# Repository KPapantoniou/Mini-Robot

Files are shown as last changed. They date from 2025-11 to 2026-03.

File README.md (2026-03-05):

### Modeling, Simulation, and Autonomous Control

> Master's Thesis — *K. Papantoniou*
> 📄 [Read the full thesis](presentation_thesis/thesis_KPapantoniou.pdf)

---

## What Is This?

Most robots move using wheels, legs, or tracks. This one moves using **vibrations**.

By spinning two small eccentric masses at controlled speeds, the robot generates asymmetric centrifugal forces that cause it to inch forward, backward, and rotate — with no conventional drivetrain. The result is an ultra-compact, mechanically simple platform capable of autonomous 2D navigation.

This repository contains everything built for the thesis: the physics simulation that validated the model, the embedded firmware and PC-side controller that runs on real hardware, and the computer vision pipeline that lets the robot navigate autonomously to a user-defined target.

---

## How the Pieces Fit Together

The project is structured in three layers that build on each other:

```
┌─────────────────────────────────────────────────────┐
│               SIMULATION (C++)                      │
│  Physics model · Motor dynamics · PID tuning        │
│  Validates behavior before touching hardware        │
└──────────────────────┬──────────────────────────────┘
                       │ validated parameters
                       ▼
┌─────────────────────────────────────────────────────┐
│            EMBEDDED CONTROLLER (ESP32)              │
│  Firmware receives UDP commands from PC             │
│  PID loop maintains target RPM per motor            │
└──────────────────────┬──────────────────────────────┘
                       │ position & orientation
                       ▼
┌─────────────────────────────────────────────────────┐
│         COMPUTER VISION CONTROLLER (C++/Python)     │
│  Camera detects robot markers in real time          │
│  Macro + Micro control closes the navigation loop   │
└─────────────────────────────────────────────────────┘
```

The simulation de-risks the design: motor dynamics, PID parameters, and force profiles are all validated in software first. Those parameters then go directly into the firmware. The vision system closes the outer loop, giving the robot a sense of where it is in the world.

---

## Repository Structure

```
├── simulation/              # C++ physics simulation
│   ├── src/                 # Motor, robot, force, PID models
│   ├── ploter/              # Python visualization scripts
│
├── controller/
│   ├── camera_controller/   # PC-side C++ vision & control app
│   └── esp32_controller/    # ESP32 firmware (Arduino/PlatformIO)
│
├── presentation_thesis/     # Thesis PDF and presentation slides
└── cad/                     # CAD schematics of the physical platform
```
---
## The Three Components

### 🧠 Physics Simulation
*[Full details → simulation/README.md](simulation/README.md)*

The simulation models the complete electromechanical system: DC motor electrical dynamics, eccentric mass rotation, centrifugal force generation, and the resulting robot motion in 1-DOF and 2-DOF. A Simulated Annealing optimizer searches for optimal PID parameters automatically and compairs them with a PI controller with parameters that are provided by solving the linear second degree system of the close loop controller.

Key outputs: motor force profiles, robot trajectory under various control schemes, settling time analysis, and PWM-to-voltage mapping.

**Stack:** C++ · CMake · Python 

---
### ⚙️ Embedded Firmware (ESP32) + Autonomus Vision Controller
*[Full details → controller/README.md](controller/README.md)*

The ESP32 firmware handles everything on the robot side: Wi-Fi connection, UDP command reception, dual motor PWM control, and a per-motor PID loop that maintains target RPM using encoder feedback. It also streams real-time RPM data back to the PC for monitoring.

A C++ application captures live camera feed, detects colored markers on the robot using HSV-space thresholding, and runs a two-tier control strategy

Commands are simple single-character tokens (`F`, `B`, `L`, `R`, `S`) sent over UDP from the PC controller.

**Stack:** C++ · Arduino/PlatformIO · WiFiUDP · OpenCV · CMake

---
## Results

The full experimental results, parameter derivations, and performance analysis are documented in the thesis:

📄 [thesis_KPapantoniou.pdf](presentation_thesis/thesis_KPapantoniou.pdf)

---

## License

Academic project — Master's Thesis. Contact the author for reuse inquiries.

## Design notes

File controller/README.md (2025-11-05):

# Physical Robot Controller

This project provides the software necessary to control a physical robot using camera-based visual feedback and UDP communication. It enables the robot to navigate to a user-defined target, offering both macro and micro-level control strategies.

### Features

* **Camera-Based Localization**: Utilizes OpenCV for real-time video processing to detect robot and target markers.
* **Two Control Modes**: Implements distinct "Macro" and "Micro" control strategies for navigation, suitable for different robot behaviors or environmental conditions.
* **UDP Communication**: Sends movement commands from the PC (controller) to an ESP32-based robot (firmware) over UDP.
* **Real-time Trajectory Plotting**: Python scripts visualize the robot's path and motor speeds in real-time.
* **Camera Calibration**: Includes a utility for calibrating the camera to convert pixel coordinates to real-world measurements (cm).
* **Video Recording**: Option to record the control session video for later analysis.
* **User Interaction**: Allows users to set a target by clicking on the video feed and control the robot with keyboard commands.
Note: the path for the trajectories output data and the videos are hardcoded for the system. You may want to modify the paths.
### Components

The project consists of two main parts: the PC-side controller (C++ application) and the ESP32 firmware.

#### PC-side Controller (C++)

* `main.cpp`: The primary application file that initializes the camera, sets up mouse callback for target selection, handles video capture and recording, and integrates the different robot controllers.
* `camera_calibrator.h`/`camera_calibrator.cpp`: Manages camera calibration to establish a pixel-to-centimeter ratio, crucial for accurate robot movement calculations.
* `udp_client.h`/`udp_client.cpp`: Handles the UDP client-side communication, sending commands to the ESP32.
* `robot_controller.h`/`robot_controller.cpp`: Abstract base class defining the interface for robot movement calculation and marker detection. Provides core functionalities like distance and angle calculation.
* `macro_controller.h`/`macro_controller.cpp`: Implements the "Macro" control strategy, likely for larger movements or reaching general areas, using color-based marker detection for the front and rear of the robot.
* `micro_controller.h`/`micro_controller.cpp`: Implements the "Micro" control strategy, potentially for fine-tuned adjustments or precise positioning, using marker detection and contour analysis to find the front tip.

#### ESP32 Firmware (Arduino/C++)

* `main_esp.cpp`: The firmware for the ESP32 micro-controller. It handles Wi-Fi connection, UDP server setup to receive commands from the PC, motor control (PWM), and PID control for maintaining motor speeds based on sensor feedback. It also sends debug information back to the PC.

#### Python Scripts

* `trajectory_plot.py`: A script to read `robot_path.csv` (generated by the C++ controller) and plot the robot's trajectory, X and Y positions over time, and Y vs X position.
* `commands_animation.py`: A script that acts as a keyboard interface to send UDP commands to the ESP32 and visualizes real-time motor RPMs (Motor A and B) received as debug logs from the ESP32.
* `parameters_pwm`: A script to solve the polynomial equation for the mapping of the PWM values with the actual output voltage.
* `ts_calculation`: A script that finds the settling time based on the differential equation for the behavior of the motor and the maximum value of 1.5 V of the motor in use.

### Getting Started

#### Prerequisites

* **PC-side:**
    * C++ compiler (e.g., g++ for Linux/macOS, MSVC for Windows)
    * CMake (for building the C++ project)
    * OpenCV library (for camera operations and image processing)
    * Python 3.x
    * Python packages: `pandas`, `matplotlib`, `keyboard`, `socket` (standard library), `threading` (standard library), `re` (standard library).
* **ESP32-side:**
    * Arduino IDE or PlatformIO
    * ESP32 board package
    * WiFi and WiFiUdp libraries (standard Arduino libraries)

#### Installation and Setup

1.  **PC-side Controller (C++):**
    * Ensure OpenCV is installed and configured for your C++ environment.
    * Navigate to the C++ controller directory (e.g., `final/controller/camera_controller/`).
    * Build using CMake:
        ```bash
        mkdir build
        cd build
        cmake ..
        make # On Linux/macOS
        # On Windows, use `cmake --build .` or open the generated .sln in Visual Studio
        ```
    * The executable will be generated in the `build` directory.

2.  **ESP32 Firmware:**
    * In final/controller/esp32_controller/src
    * Open `main.cpp` in Arduino IDE or PlatformIO.
    * Update `ssid` and `password` with your Wi-Fi network credentials.
    * Update `debugPC_IP` and `ESP32_IP` in `commands_animation.py` and `main_esp.cpp` to match your PC's and ESP32's IP addresses respectively.
    * Upload the code to your ESP32 board.

### Usage

1.  **Run the PC-side Controller:**
    ```bash
    ./build/RobotController # Or the appropriate path/executable name
    ```
    * The application will display a camera feed.
    * **Calibration**: If not already calibrated, follow the on-screen instructions or use the `CameraCalibrator` to click points and calculate the `cmPerPixel` ratio. The calibration data can be saved and loaded from a file.
    * **Target Selection**: Click on the video feed to set a target for the robot.
    * **Video Recording**: You will be prompted to record the session. Enter 'y' or 'n'. If 'y', provide a filename.

2.  **Control the Robot (via `commands_animation.py`):**
    ```bash
    python commands_animation.py
    ```
    * This script will open a plot for real-time RPM visualization and allow sending commands.
    * **Controls:**
        * `w`: Forward
        * `s`: Backward
        * `a`: Difference in motor speeds in order to turn a little to the left
        * `d`: Difference in motor speeds in order to turn a little to the right
        * `space`: Stop Motors
        * `+`: Increase Speed
        * `-`: Decrease Speed
        * `q`: Quit (stops the animation and command loop)
        * `l`: Measure UDP Latency

### How it Works
#### Camera & Marker Detection
The system uses OpenCV for real-time video processing. It converts the camera feed to HSV color space to facilitate color-based marker detection.
* **Macro Controller**: Detects two distinct colored markers (e.g., orange for rear, blue for front) on the robot to determine its orientation and position.
* **Micro Controller**: Detects a single colored marker (e.g., yellowish) and uses contour analysis to find the "tip" of the robot, which is used as the front point.
* The `camera_calibrator` is used to establish the `cmPerPixel` ratio, allowing the system to translate pixel coordinates from the camera feed into real-world centimeter measurements, enabling accurate distance and position calculations for navigation.

#### Robot Movement Control

The `RobotController` base class calculates distances and angles between the robot's current position/orientation and the target.
* **Macro Control**: Based on the angle between the robot's current direction and the target, it issues 'L' (left) or 'R' (right) commands for rotation, and 'C' (continue) for forward movement once aligned. It can also issue 'F' (forward) and 'B' (backward) commands directly.
* **Micro Control**: This controller focuses on reaching the target precisely. If the distance to the target is within a `stopAcceptancePixels` threshold, it issues a 'S' (stop) command. Otherwise, it issues a 'F' (forward) command.
* Commands ('F', 'L', 'R', 'S', '+', '-') are sent via UDP to the ESP32.

#### ESP32 Motor Control

The `main_esp.cpp` firmware on the ESP32 receives UDP commands. It uses these commands to:
* Control two DC motors via PWM (Pulse Width Modulation) using specific pins defined in the code.
* Implement a PID control loop for each motor to maintain a target RPM. The RPM is measured using attached sensors, and the PID controller adjusts the motor voltage (PWM duty cycle) to minimize the error between the target and actual RPM.
* The ESP32 sends debug messages back to the PC, including real-time RPM values for both motors, which are then visualized by `commands_animation.py`.

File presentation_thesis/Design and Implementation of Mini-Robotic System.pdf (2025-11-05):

# Σχεδίαση και Υλοποίηση ενός Μίνι-Ρομποτικού Συστήματος

## ΚΩΝΣΤΑΝΤΙΝΟΣ ΠΑΠΑΝΤΩΝΙΟΥ – ΧΑΤΖΗΓΙΩΣΗΣ

## ΔΙΠΛΩΜΑΤΙΚΗ ΕΡΓΑΣΙΑ

## ΕΠΙΒΛΕΠΩΝ: ΚΩΣΤΑΣ ΒΛΑΧΟΣ

ΤΜΉΜΑ ΜΗΧ. Η/Υ & ΠΛΗΡΟΦΟΡΙΚΉΣ

ΠΑΝΕΠΙΣΤΉΜΙΟ ΙΩΑΝΝΊΝΩΝ

DEPARTMENT OF COMPUTER SCIENCE & ENGINEERING

UNIVERSITY OF IOANNINA

# Μίνι – Ρομπότ με βάση Φυγοκεντρικές Δυνάμεις

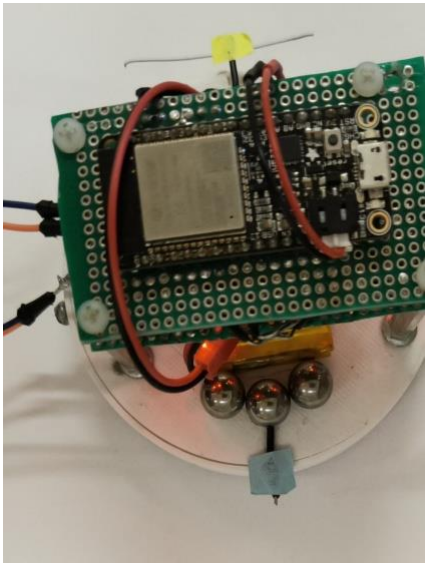
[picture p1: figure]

Το τελικό mini-robot

•Σκοπός:
•Σχεδίαση και ανάπτυξη καινοτόμου ρομποτικού συστήματος διαστάσεων εκατοστών βασισμένων σε κίνηση με δονήσεις. •Αξιοποίηση φυγοκεντρικών δυνάμεων για απλούστευση και μείωση κόστους σε σχέση με συμβατικές μεθόδους.
•Κίνηση σε κλίμακα μικρομέτρων.
•Σχεδίαση & Υλοποίηση:
•Ολοκληρωμένη διαδικασία: μαθηματική μοντελοποίηση, προσομοίωση και κατασκευή του ρομπότ.
•Πειραματική αξιολόγηση της λειτουργίας του συστήματος.

# Η Σημασία της Μικρο-ρομποτικής

•Βιοϊατρικές Εφαρμογές
•Μικρο-συναρμολόγηση
•Περιβαλλοντική
τεχνολογία

## Εφαρμογές

•Πολυπλοκότητα
Μηχανισμών Κίνησης
•Υψηλή Κατανάλωση
Ενέργειας
•Υψηλό Κόστος

## Προκλήσεις

•Μειωμένη
Πολυπλοκότητα και
Χαμηλή Κατανάλωση
•Λειτουργία σε μη-ιδανικό περιβάλλον
•Αυτόνομη κίνηση

## Ανάγκη

Ιατρικό μικρο-ρομπότ¹ | Μικρο-ρομπότ² | MICRON Έρευνα³
1. https://www.thehindubusinessline.com/business-tech/medical-micro-bots-cruising-towards-reality/article67665445.ece 2. https://www.openaccessgovernment.org/a-millimetre-sized-microrobot-with-an-artificial-brain/99886/
3. MICRON: Small Autonomous Robot for Cell Manipulation Applications | 4

# Μικρο-ρομποτική με Δονήσεις

Εναλλακτική κίνηση με δόνηση σε σχέση με παραδοσιακές.

### Πλεονεκτήματα:

➢Απλοποιημένος σχεδιασμός και κατασκευή.
➢Δυνατότητα λειτουργίας χωρίς πολύπλοκους μηχανισμούς κίνησης.
➢Ικανότητα μετακίνησης σε δύσκολα ή περιορισμένα περιβάλλοντα.

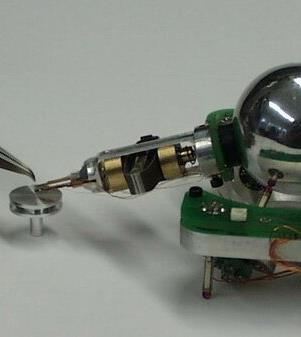
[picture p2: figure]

MICRON ROBOT III

# Πιεζοηλεκτρικά Συστήματα και Σφιγκτήρες

Πρώτο Παράδειγμα Δονητικής Μικρορομποτικής: ❖ Βάση Λειτουργίας:
- Πιεζοηλεκτρικά: Υλικά που μεταβάλλουν το μέγεθος με ηλεκτρικό πεδίο.
- Ηλεκτρομαγνητικοί σφιγκτήρες: Σταθεροποίηση του ρομπότ για ώθηση σε συγκεκριμένο άξονα.
❖ Μετατροπή Δόνησης σε Μετατόπιση:
- Συγκρατημένη Κίνηση: Εναλλασσόμενη ενεργοποίηση για διαδοχικά μικρά βήματα.
- Αποτέλεσμα: Καθαρή μετατόπιση.
❖ Περιορισμοί:
- Υψηλό κόστος: Λόγο απαιτήσεων σε υψηλή τάση και υλοποίηση.
- Ασυνεχής κίνηση: Διακριτή και όχι ομαλή μεταφορά.
- Πολυπλοκότητα: Δύσκολη μαθηματική μοντελοποίηση για πρόβλεψη κίνησης.

Πιεζοηλεκτρικός Κινητήρας⁴

Αναλυτικό Σχέδιο του Επενεργητή για πιζοηλεκτρικο μηχανισμό4

4. Tiny Silent Linear Cybernetic Actuator Driven by Piezoelectric Device with Electromagnetic Clamp 6

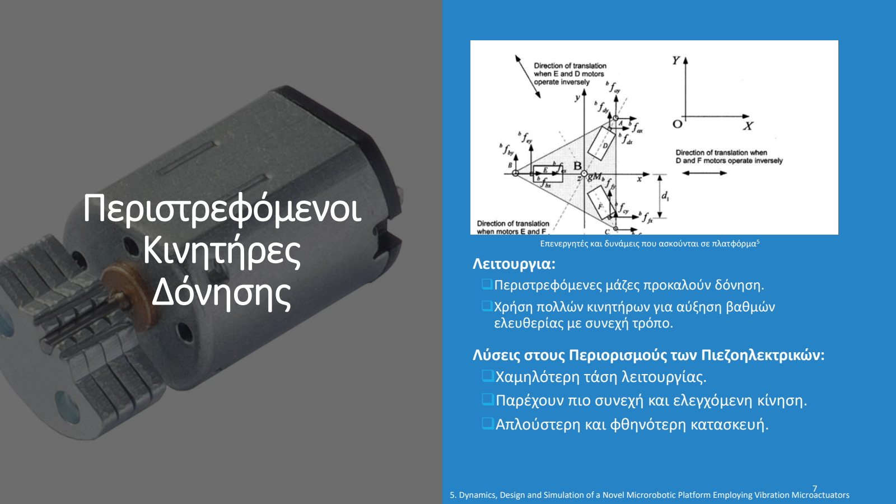
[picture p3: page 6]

# Περιστρεφόμενοι Κινητήρες Δόνησης

Λειτουργια:
❑Περιστρεφόμενες μάζες προκαλούν δόνηση.
❑Χρήση πολλών κινητήρων για αύξηση βαθμών ελευθερίας με συνεχή τρόπο.

Λύσεις στους Περιορισμούς των Πιεζοηλεκτρικών: ❑Χαμηλότερη τάση λειτουργίας.
❑Παρέχουν πιο συνεχή και ελεγχόμενη κίνηση. ❑Απλούστερη και φθηνότερη κατασκευή.

Επενεργητές και δυνάμεις που ασκούνται σε πλατφόρμα⁵

5. Dynamics, Design and Simulation of a Novel Microrobotic Platform Employing Vibration Microactuators 7

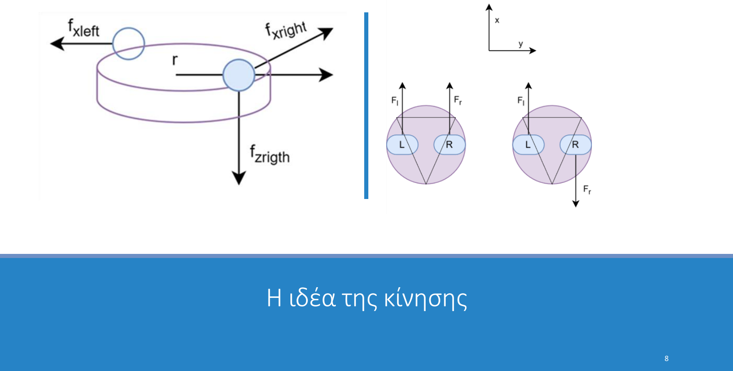
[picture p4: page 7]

# Η ιδέα της κίνησης

# Ηλεκτρικό Μοντέλο DC Κινητήρα Δόνησης

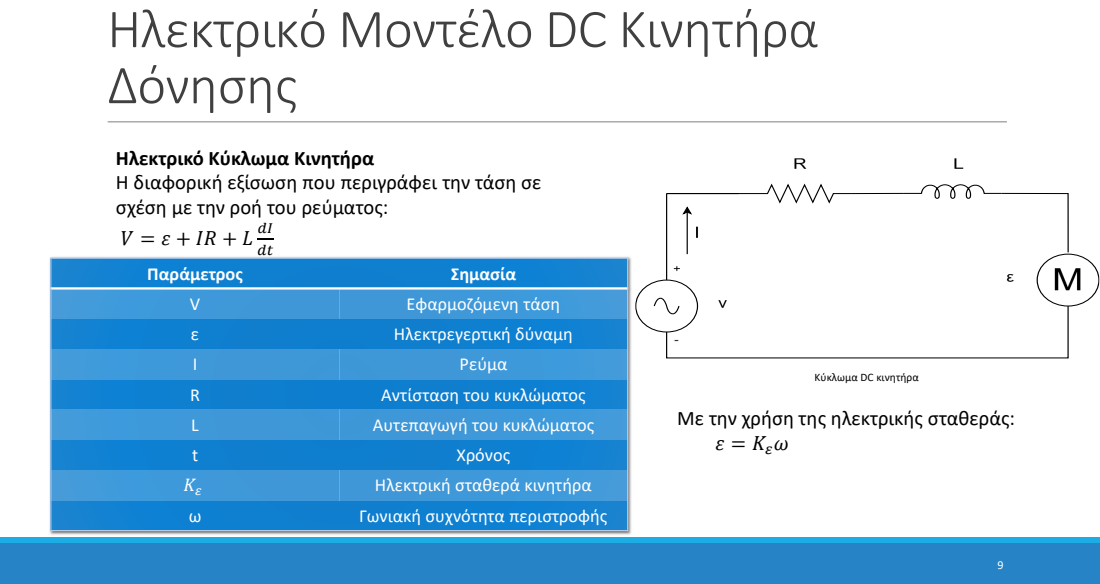
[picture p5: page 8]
Ηλεκτρεγερτική δύναμη; Ρεύμα; Αντίσταση του κυκλώματος; Αυτεπαγωγή του κυκλώματος; Χρόνος; Ηλεκτρική σταθερά κινητήρα; Γωνιακή συχνότητα περιστροφής

Ηλεκτρικό Κύκλωμα Κινητήρα
Η διαφορική εξίσωση που περιγράφει την τάση σε
σχέση με την ροή του ρεύματος:

Παράμετρος Σημασία
V | Εφαρμοζόμενη τάση

Κύκλωμα DC κινητήρα

Με την χρήση της ηλεκτρικής σταθεράς:
ε = Kεω

# Ηλεκτρικό Μοντέλο DC Κινητήρα Δόνησης

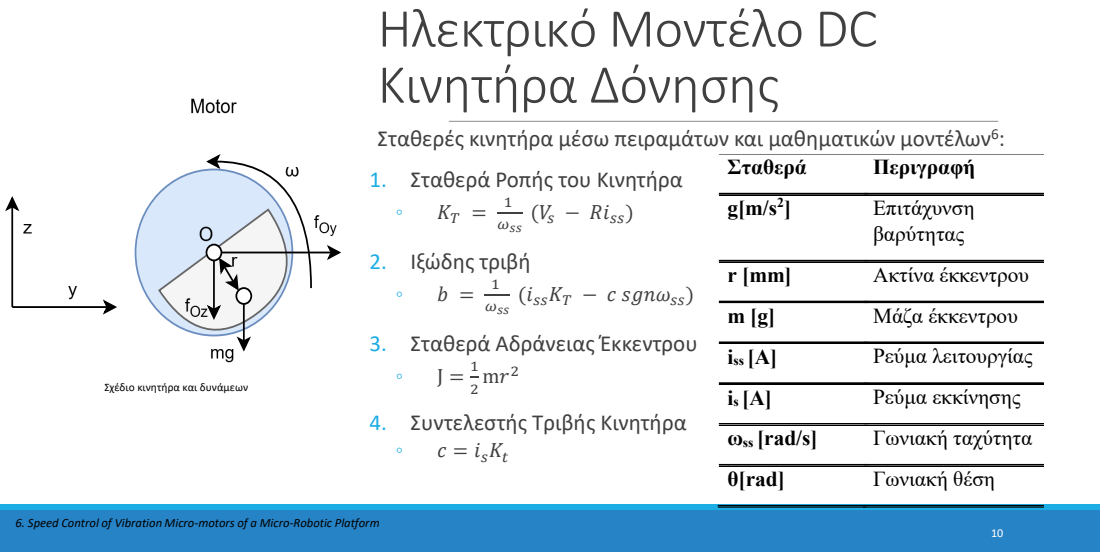
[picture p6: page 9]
ωss; (Vs − Riss); 2. Ιξώδης τριβή; (issKT − c sgnωss); Σταθερά; Περιγραφή; Επιτάχυνση; βαρύτητας; Ακτίνα έκκεντρου; Μάζα έκκεντρου; iss [A]; Ρεύμα λειτουργίας; Ρεύμα εκκίνησης; ωss [rad/s]; Γωνιακή ταχύτητα; θ[rad]; Γωνιακή θέση

Σταθερές κινητήρα μέσω πειραμάτων και μαθηματικών μοντέλων⁶
1. Σταθερά Ροπής του Κινητήρα

3. Σταθερά Αδράνειας Έκκεντρου

Σχέδιο κινητήρα και δυνάμεων

4. Συντελεστής Τριβής Κινητήρα
◦ c = isKt

6. Speed Control of Vibration Micro-motors of a Micro-Robotic Platform

# Προσομοίωση Μοντέλου Κινητήρα

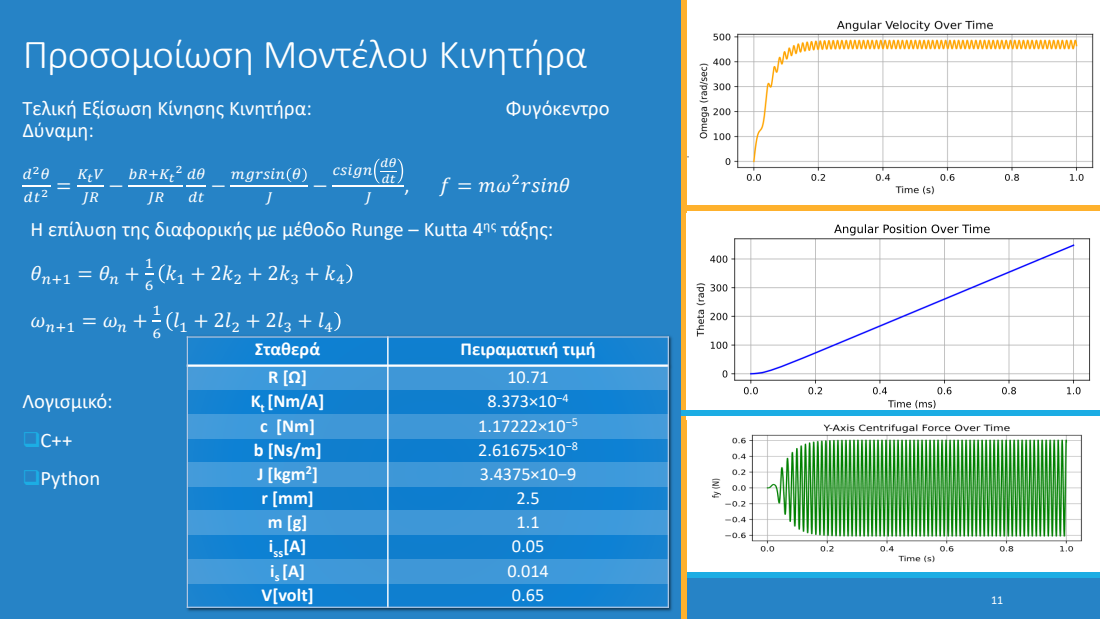
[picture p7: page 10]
Τελική Εξίσωση Κίνησης Κινητήρα:; Φυγόκεντρο; mgrsin; csign dθ dt; rsinθ; Η επίλυση της διαφορικής με μέθοδο Runge; – Kutta; ης τάξης:; Λογισμικό: ❑C++ ❑Python; V[volt]

Δύναμη: d²θ dt² = Kt

Σταθερά | Πειραματική τιμή
R [Ω] | 10.71
Kt [Nm/A] | 8.373 ×10⁻⁴
c [Nm] | ×10⁻⁵ 1.17222
b [Ns/m] | ×10⁻⁸ 2.61675
2 J [kgm ] | 3.4375 ×10−9
r [mm] | 2.5
m [g] | 1.1 i
ss[A] | 0.05
i s [A] | 0.014

# Δυναμική Πλατφόρμας

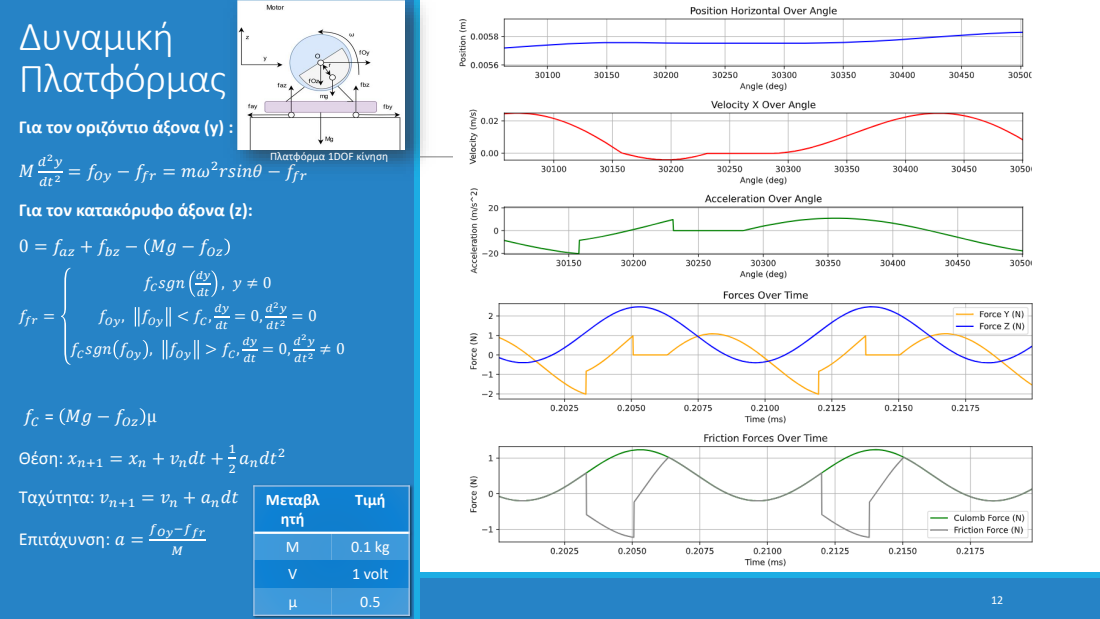
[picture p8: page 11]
fOy; ffr; rsinθ; Για τον κατακόρυφο άξονα (; faz; fbz; fOz; fCsgn; Θέση:; vndt; ndt; Ταχύτητα:; Επιτάχυνση:; Μεταβλ ητή; Τιμή; 1 volt μ; Πλατφόρμα 1DOF κίνηση

Για τον οριζόντιο άξονα (

# Συνολική Δυναμική: Η Κίνηση του

Ρομπότ 1.

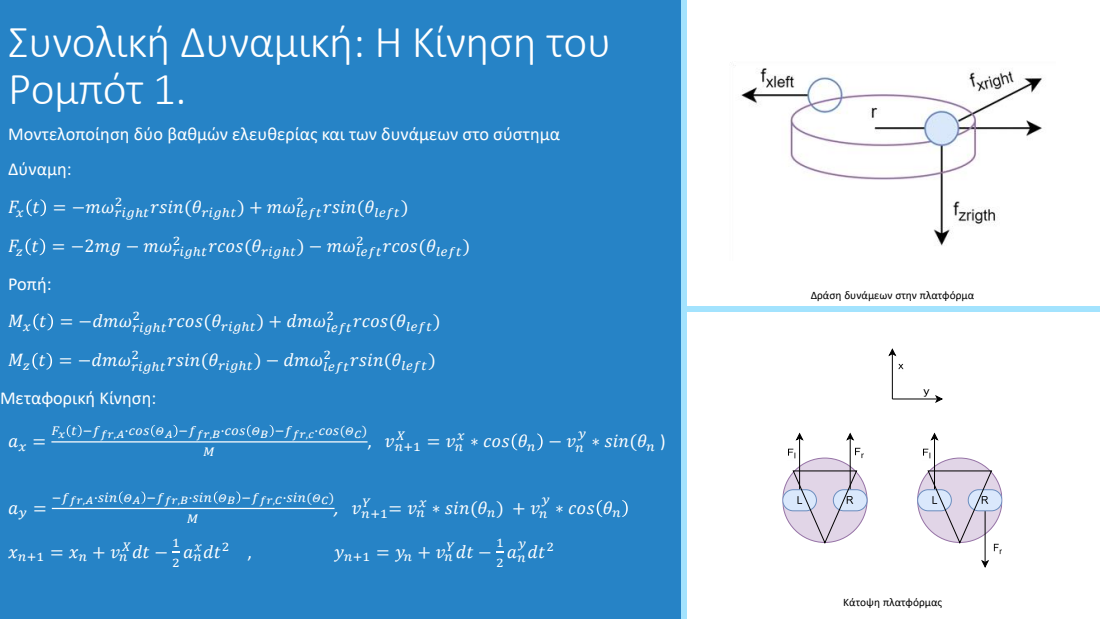
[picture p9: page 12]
Δύναμη:; Fx t = −mωrigℎt; rsin(θleft); t = −2mg − mωrigℎt; rcos(θleft); Ροπή:; Mx t = −dmωrigℎt; t = −dmωrigℎt; Μεταφορική Κίνηση:; ∗ sin(θn ); ∗ cos θn; Xdt −; xdt²; Ydt −; dt²; Κάτοψη πλατφόρμας

Μοντελοποίηση δύο βαθμών ελευθερίας και των δυνάμεων στο σύστημα

rsin(θrigℎt) + mωleft

rcos(θrigℎt) − mωleft

Δράση δυνάμεων στην πλατφόρμα

rcos(θrigℎt) + dmωleft

rsin(θrigℎt) − dmωleft

Fx t −ffr,Α∙cos ΘΑ −ffr,B∙cos ΘΒ −ffr,c∙cos(ΘC)

∗ cos θn − vn

−ffr,A∙sin ΘΑ −ffr,B∙sin ΘΒ −ffr,C∙sin(ΘC)

∗ sin(θn) + vn

# Συνολική Δυναμική: Η Κίνηση του

Ρομπότ 2.

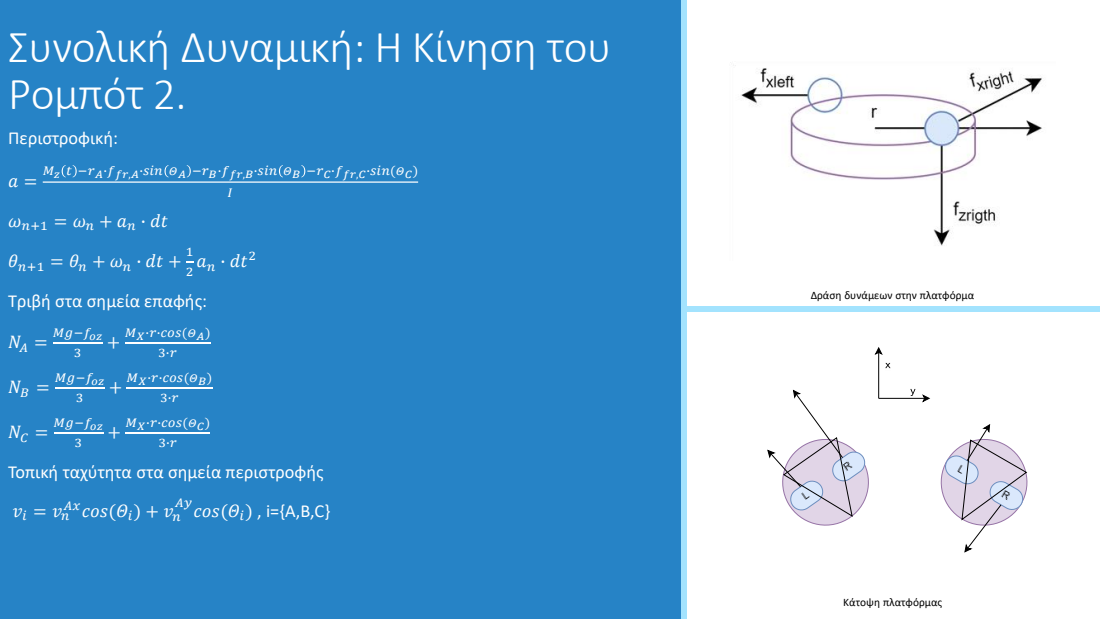
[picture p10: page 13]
Περιστροφική:; an ∙ dt²; Mg−foz; MX∙r∙cos(ΘΑ); MX∙r∙cos(ΘΒ); cos(Θi) , i={A,B,C}; Κάτοψη πλατφόρμας

Mz t −rA∙ffr,A∙sin ΘΑ −rB∙ffr,B∙sin ΘΒ −rC∙ffr,C∙sin(ΘC)

Τριβή στα σημεία επαφής:

Δράση δυνάμεων στην πλατφόρμα

MX∙r∙cos(ΘC)

Τοπική ταχύτητα στα σημεία περιστροφής

Axcos(Θi) + vn

# Προσομοίωση συνολικής κίνησης: Σύγχρονη

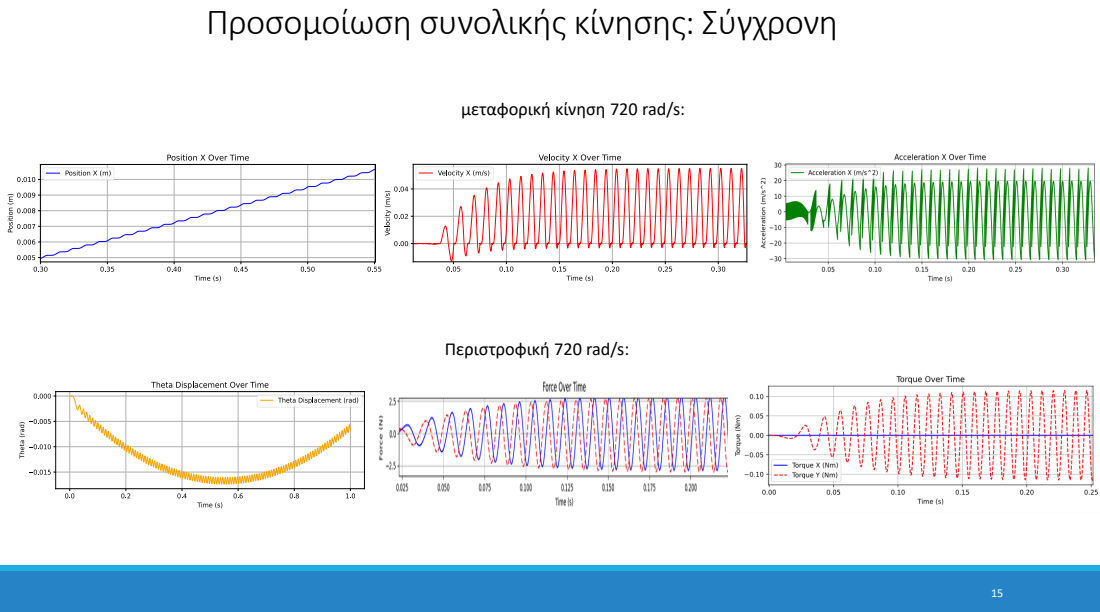
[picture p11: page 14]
Περιστροφική 720 rad/s:

μεταφορική κίνηση 720 rad/s:

# Προσομοίωση συνολικής κίνησης: Ασύγχρονη

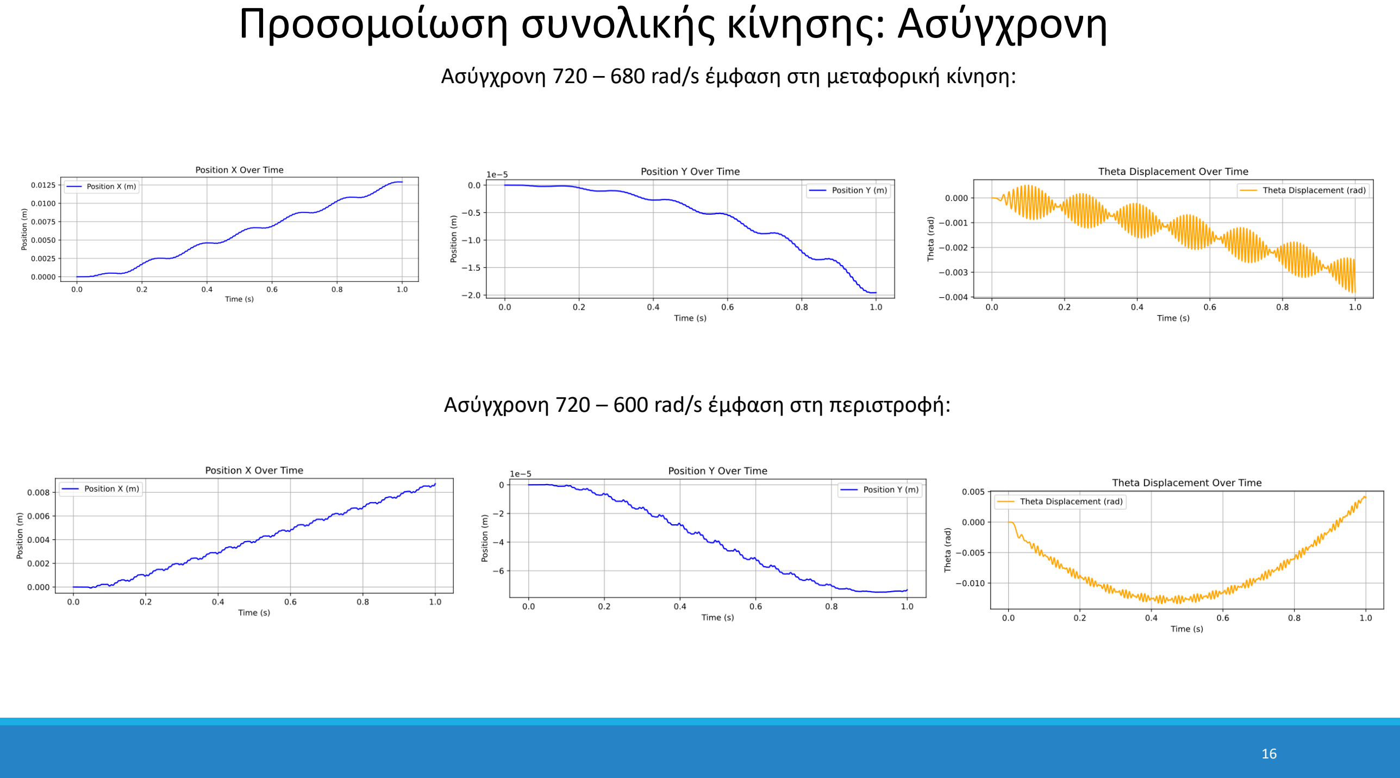
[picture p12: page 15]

Ασύγχρονη 720 – 680 rad/s έμφαση στη μεταφορική κίνηση:

Ασύγχρονη 720 – 600 rad/s έμφαση στη περιστροφή:

## ESP32-WROOM-32E: Εγκέφαλος του Μικρορομπότ

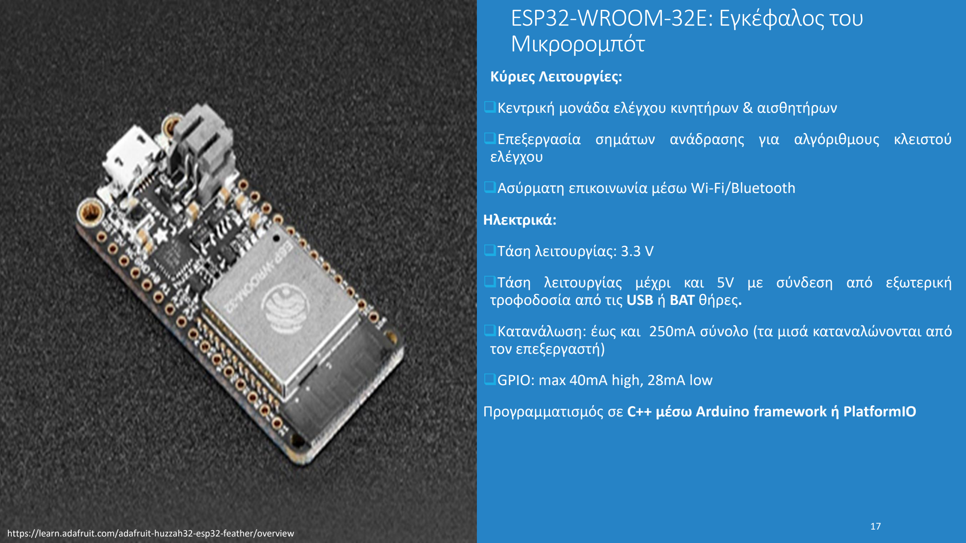
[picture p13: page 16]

Κύριες Λειτουργίες:

❑Κεντρική μονάδα ελέγχου κινητήρων & αισθητήρων

❑Επεξεργασία σημάτων ανάδρασης για αλγόριθμους κλειστού ελέγχου

❑Ασύρματη επικοινωνία μέσω Wi-Fi/Bluetooth

Ηλεκτρικά:

❑Τάση λειτουργίας: 3.3 V

❑Τάση λειτουργίας μέχρι και 5V με σύνδεση από εξωτερική τροφοδοσία από τις USB ή BAT θήρες.

❑Κατανάλωση: έως και 250mA σύνολο (τα μισά καταναλώνονται από τον επεξεργαστή)

❑GPIO: max 40mA high, 28mA low

Προγραμματισμός σε C++ μέσω Arduino framework ή PlatformIO

https://learn.adafruit.com/adafruit-huzzah32-esp32-feather/overview | 17

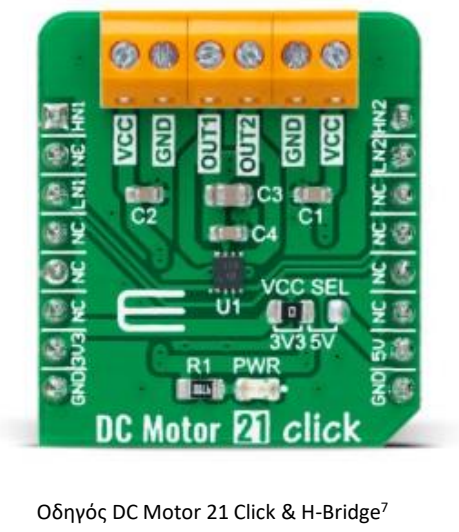
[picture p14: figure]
Οδηγός DC Motor 21 Click & H-Bridge⁷

# Οδηγοί Κινητήρων (DC Motor 21 Click & H-Bridge)

❖Λειτουργικός Ρόλος:
- Ενισχυτές ρεύματος για λειτουργία κινητήρων.
- Αποφυγή υπερφόρτωσης του μικροελεγκτή και προστασία από αντιηλεκτρεγερτική δύναμη δύναμη (Back - EMF).

❖Κυκλωματική Αρχή – H-Bridge:

### Το H-Bridge αποτελείται από 4 τρανζίστορ που επιτρέπουν:

- Δεξιόστροφη / Αριστερόστροφη κίνηση
- Αδράνεια, Φρενάρισμα, ή Βραχυκύκλωση

Ελέγχεται μέσω συνδυασμού σημάτων S1-S4

❖Συμβατότητα & Χαρακτηριστικά:
- Τάση λειτουργίας: 3.3V – 5V
- Μέγιστο ρεύμα εξόδου: ~500 mA ανά κινητήρα
- Υποστήριξη PWM σημάτων για έλεγχο ταχύτητας μέσω ESP32
7. https://www.mikroe.com/dc-motor-21-click?srsltid=AfmBOor_yz2MNT-W81Nv9uzdUoL4KWeGaPXu5dfagDk-2rOpEXulf8FW | H-Bridge

# DC Motors

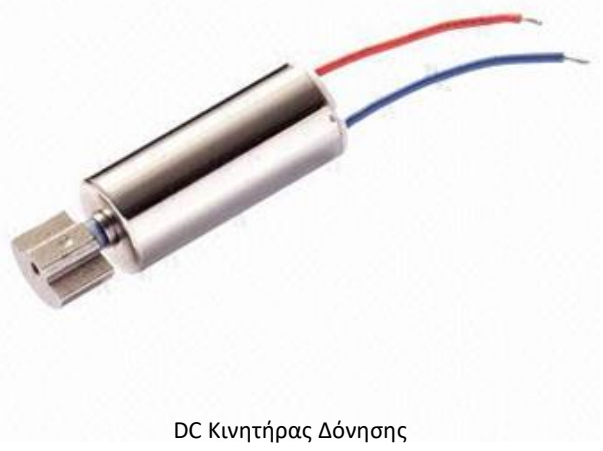
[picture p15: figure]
DC Κινητήρας Δόνησης

Τύπος & Λειτουργία

- Κινητήρες
συνεχόμενους
ρεύματος
- Έκκεντρα παράγουν
φυγόκεντρο δύναμη
με την περιστροφή
τους

Χαρακτηριστικά

- Τάση λειτουργίας:
~1.5V
- Στροφές χωρίς
φορτίο: ~11,000
RPM
- Μέση κατανάλωση
ρεύματος: ~ 50mA
- Ελάχιστη
κατανάλωση για
την εκκίνηση
περιστροφής:
~14mA

Έλεγχος &
Επικοινωνία
- Η ταχύτητα της
περιστροφής του
έκκεντρου
ελέγχεται με
ακρίβεια μέσο
σήματα PWM
- Η Κατεύθυνση της
περιστροφής
εξαρτάται από την
πόλωση του
κινητήρα

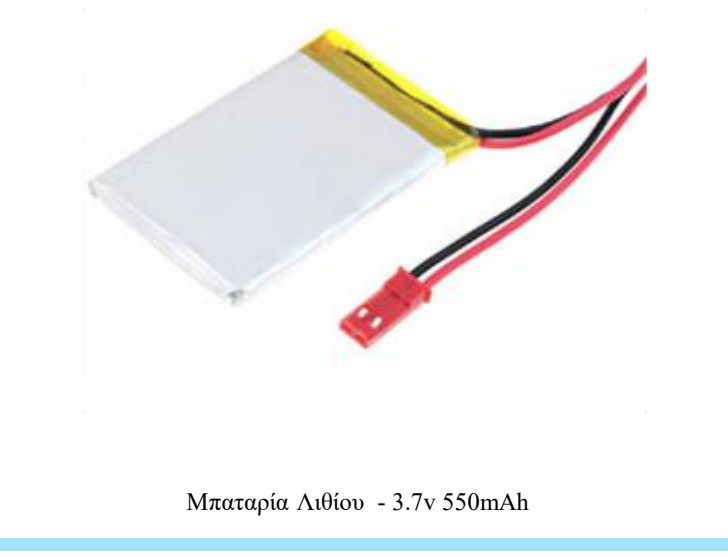
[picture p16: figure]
Μπαταρία Λιθίου - 3.7v 550mAh

# Μπαταρία LiPo & Αισθητήρας Hall

❖ LiPo – 3.7V 550mAh
- Σταθερή τάση και συνεχές ρεύμα για το σύστημα.
- Επαρκή χωρητικότητα για περίπου 1 ώρα ασύρματης λειτουργίας.
- Ασφαλής τροφοδοσία (δεν υπερβαίνει τα 5V).

❖Πειραματική Προσέγγιση Μέτρησης Ταχύτητας
- Μαθηματικές προσεγγίσεις με βάση την τάση και το φορτίο του κινητήρα.
- Back-EMF ανάλυση στην λειτουργία και ενσωμάτωσή της στα μαθηματικά μοντέλα.

❖Τελική Λύση – Μαγνητικοί Αισθητήρες Hall + Μαγνήτης
- Χρήση Hall αισθητήρων σε συνδυασμό με μαγνήτες κολλημένους στα εκκεντρικά βάρη.
- Κάθε περιστροφή παράγει παλμούς που χρησιμοποιούνται για την μέτρηση γωνιακής ταχύτητας.
- Επιλογή που προσφέρει αξιοπιστία, ακρίβεια και ενσωμάτωση σε αλγόριθμους κλειστού βρόγχου.

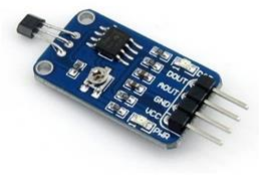
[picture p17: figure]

Hall Sensor

# Τελική Συνδεσμολογία

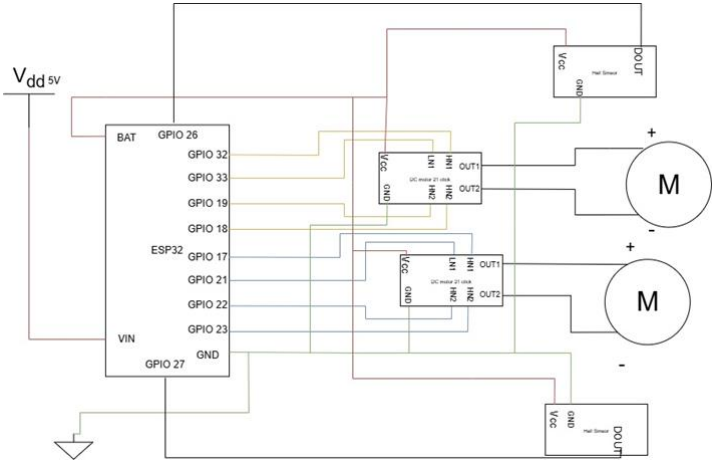
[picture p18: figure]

Αναλυτικό Σχέδιο Κυκλώματος

### - ESP32→ Driver (x2): 4 PIN (x2)

### - Driver → Κινητήρας (x2): 2 PIN (x2)

### - ESP32 → Hall Sensors (x2): 1 PIN (x2)

### - Μπαταρία → Όλο το κύκλωμα: 5 PIN

### - Γειώσεις (GND): 5 PIN

# Ασύρματος Επικοινωνία με Ελαχιστοποίηση Καθυστέρησης

### BLUETOOTH ΕΠΙΚΟΙΝΩΝΙΑ

Το Bluetooth Classic (ή BLE) προσφέρει:

- Πλεονεκτήματα:
- Χαμηλή κατανάλωση ενέργειας
- Εύκολη σύζευξη με φορητούς υπολογιστές
- Εύκολη χρήση μέσο απλών εφαρμογών (putty)
- Απλό πρωτόκολλο
- Μειονεκτήματα:
- Χαμηλό bitrate (~1 Mbps BLE)
- Υψηλότερο latency για real-time επικοινωνία (συνήθως ~20ms)
- Μειωμένη αξιοπιστία σε πολυπλοκότερες εφαρμογές κλειστού ελέγχου

### WI-FI UDP ΠΡΩΤΟΚΟΛΛΟ

Το ESP32 προσφέρει επικοινωνία Wi-Fi μέσω πρωτοκόλλων UDP. Επιλέχθηκε το UDP για τις δοκιμές λόγω:

- Πλεονεκτήματα:
- Υψηλό bitrate (μέχρι 54 Mbps, θεωρητικά)
- Ελάχιστο latency (~5ms σε ίδιες συνθήκες)
- Υποστήριξη real-time ανανέωσης τιμών ελέγχου (π.χ. θέση, ταχύτητα)
- Μειονεκτήματα:
- Ελαφρώς αυξημένη κατανάλωση ισχύος σε σύγκριση με BLE
- Απαιτεί χειροκίνητη διαχείριση αποσυνδέσεων και ασφαλείας
- Απαιτεί εγκαθίδρυση επικοινωνίας μέσο προγραμματισμού για επικοινωνία με udp.

Τελική Επιλογή: Wi-Fi (UDP)

# Τελική Συναρμολόγηση & Κατασκευή του Ρομπότ

➢Σχεδιασμός & Εκτύπωση Πλατφόρμας
- Σχεδιάστηκε με TinkerCAD.
- Υλοποιήθηκε με 3D εκτύπωση (Creality CR-10s Pro, PLA)
- Στόχος: επεκτάσιμη και στιβαρή βάση

➢Διαδικασία Συναρμολόγησης
- Ηλεκτρική σύνδεση: κόλληση καλωδίων με καλάι, αισθητήρων, drivers
- Μηχανική στερέωση: χρήση αποστατών & βιδών M3 για δομική σταθερότητα
- Κεντρική τοποθέτηση μπαταρίας για ισορροπημένο κέντρο βάρους
- 3 ατσάλινες σφαίρες για σημεία επαφής

➢Πρόβλημα & Λύση στην Κίνηση
- Αστάθεια κίνησης και εκτροπή
- Προσθήκη 6 βαριδιών συμμετρικά → σταθερότητα, χαμηλό κέντρο βάρους

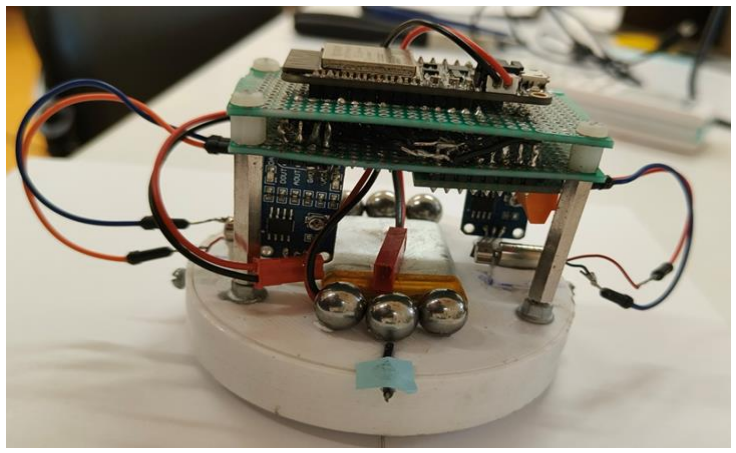
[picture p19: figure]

Τελική Μορφή Ρομπότ

CAD σχεδίαση πλατφόρμας, αριστερά το κάτω μέρος δεξιά το επάνω, τέλος ο συνδυασμός

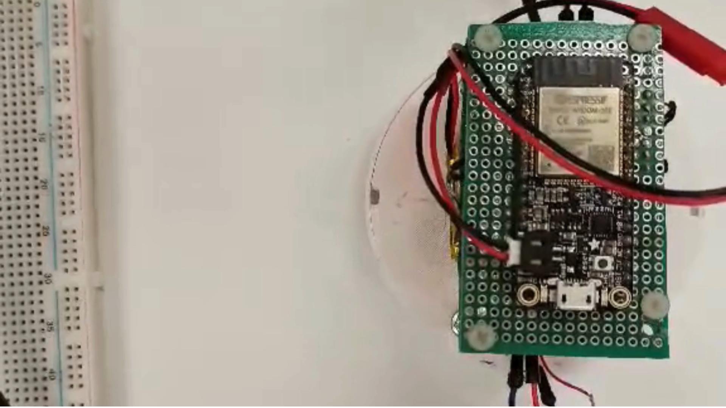
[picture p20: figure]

# Ελεύθερη κίνηση ρομπότ

## Κλειστός Βρόχος Ελέγχου με PI για ταχύτητα του κινητήρα

Τι είναι ο PI ελεγκτής;
Αναλογικός (P).
Ολοκληρωτικός (I όρος).
Ελέγχει το σφάλμα μεταξύ επιθυμητής και πραγματικής τιμής. Χρήση σε ρομποτικά και αυτοματισμούς.

Τύπος εξίσωσης:
d ׬ K + pK− = − erω =

Εύρεση παραμέτρων με ανάλυση της συνάρτησης μεταφοράς και μετασχηματισμού στο πεδίο της συχνότητας από βιβλιογραφία:
ωሷ+ Kpωሶ + Kiω = Kiωref, G s = Ω(s) Ωref(s) =

Ki
s

2 + Kps + Ki

Ki = ωn

2 =

36
ts

2

, | Kp = 2ωn =

12
ts
Settling time: ts~ 0.27 s

Αμελητέο overshoot, ελάχιστο steady-state error ακόμα και σε πολύ μικρές γωνιακές ταχύτητες.

1. Διάγραμμα – Προσομοίωση εφαρμογής του ελέγχου ταχύτητας 800rad/s.
2. Διάγραμμα – Εφαρμογή ελέγχου ταχύτητας στο φυσικό μοντέλο με δύο κινητήρες 600rad/s.

Χρήση PI: Speed Control of Vibration Micro-motors of a Micro-Robotic Platform

PI ελεγκτής

# Η Λογική της Πλοήγησης: Μηχανή Καταστάσεων

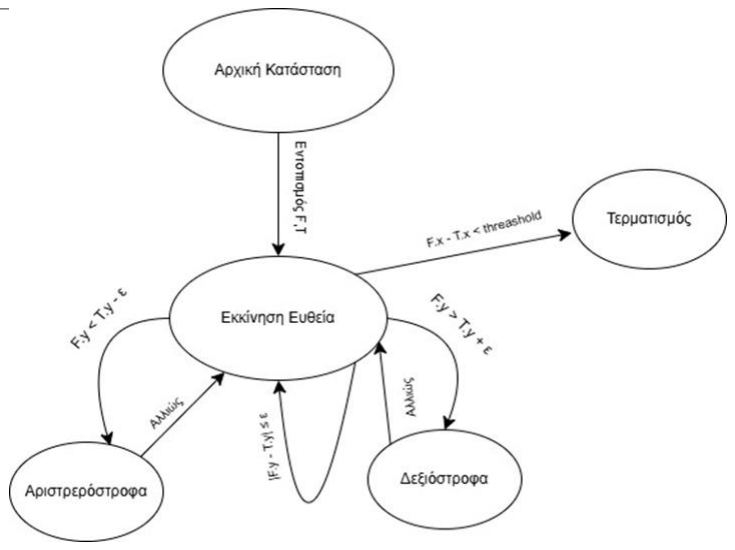
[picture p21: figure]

Αλγόριθμος 2: Finite State Machine
1: | Είσοδοι:
2: | F.y = y συντεταγμένη εμπρόσθιου μέρους ρομπότ
3: | T.y = y συντεταγμένη στόχου
4: | ε = αποδεκτό όριο σφάλματος κίνησης, σ = αποδεκτό σφάλμα σταματημού
5: | D = F.x – T.x
6: | Κατάσταση = ‘Αρχική Κατάσταση’
7: | Ενώ Εντοπίζεται F,T:
8: | Κατάσταση = ‘Εκκίνηση Ευθεία’
9: | Αν F.y < T.y – ε:
10: | Κατάσταση = ‘Αριστερόστροφη’
11: | Αλλιώς αν | F.y – T.y | ≤ ε:
12: | Κατάσταση = ‘Εκκίνηση Ευθεία’
13: | Αλλιώς:
14: | Κατάσταση = ‘Δεξιόστροφα’
15: | Αν Κατάσταση == ‘Εκκίνηση Ευθεία’
16: | Αν Κατάσταση == ‘Αριστερόστροφη’
17: | Στείλε εντολή: αύξησε ταχύτητά δεξιού κινητήρα, μείωσε του αριστερού
18: | Αλλιώς αν Κατάσταση == ‘Δεξιόστροφη’
19: | Στείλε εντολή: αύξησε ταχύτητα αριστερού κινητήρα, μείωσε του δεξιού
20: | Αν D < σ :
21: | Στείλε εντολή: σταμάτα και τους δύο κινητήρες
22: | Κατάσταση = ‘Τερματισμός’
23: | Στείλε εντολή: Κίνηση με τις τωρινές ταχύτητες των κινητήρων
24: | Αν Κατάσταση == ‘Τερματισμός’:
25: | Διέκοψε τον βρόχο

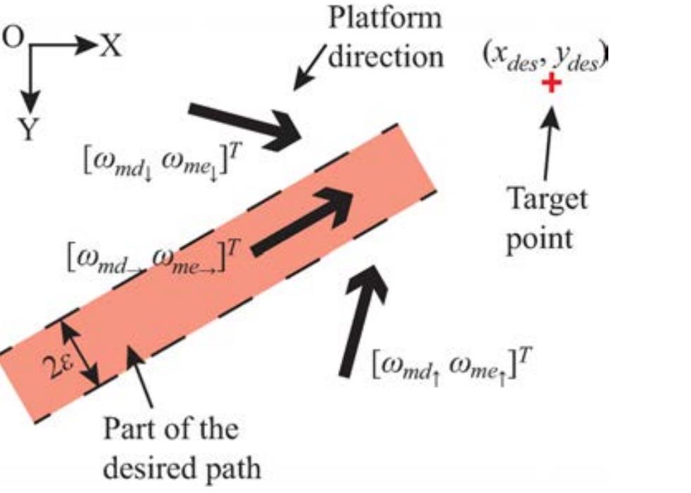
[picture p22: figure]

Αλγόριθμος από : Speed Control of Vibration Micro-motors of a Micro-Robotic Platform | 29

# Πειραματικά Αποτελέσματα: Μικροσκοπική Κίνηση

Στόχος μπροστά από το ρομπότ

Στόχος με μεγαλύτερη ακρίβεια

Στόχος εκτός της ευθείας του ρομπότ

# Πειραματικά Αποτελέσματα: Μακροσκοπική Κίνηση

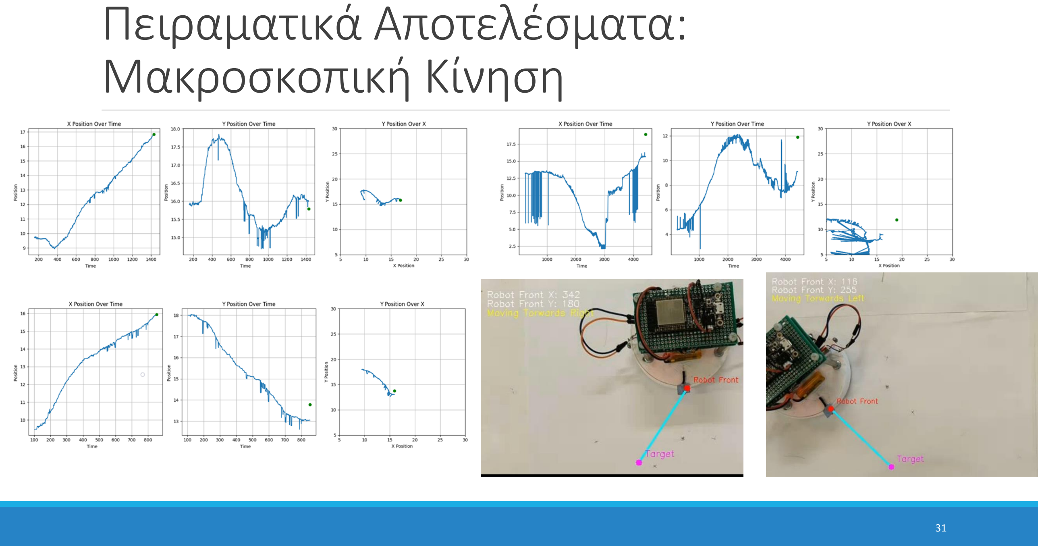
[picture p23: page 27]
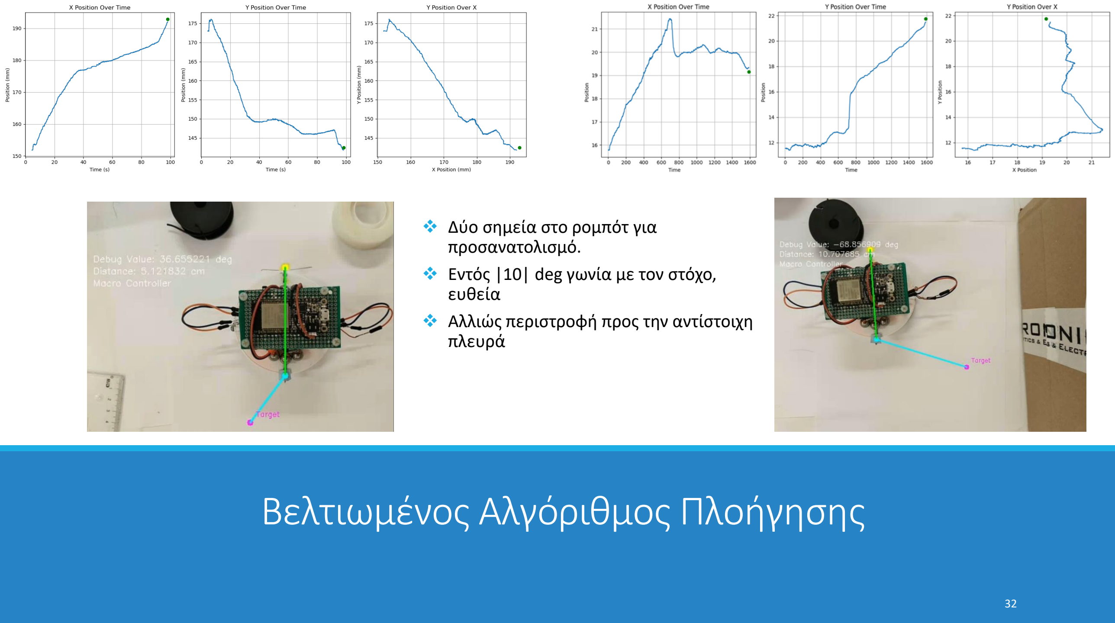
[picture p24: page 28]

# Βελτιωμένος Αλγόριθμος Πλοήγησης

❖ Δύο σημεία στο ρομπότ για προσανατολισμό.
❖ Εντός |10| deg γωνία με τον στόχο, ευθεία
❖ Αλλιώς περιστροφή προς την αντίστοιχη πλευρά

# Συμπεράσματα

❖Επιβεβαίωση της δυνατότητας σχεδίασης, κατασκευής και πειραματικής επικύρωσης ενός αυτόνομου μικρο-ρομπότ χαμηλού κόστους (~50€).

❖Εγκυρότητα των μαθηματικών μοντέλων, ομοιότητα στην προσομοίωση με τα πειραματικά αποτελέσματα.

❖Επίτευξη υψηλής ακρίβειας (εκατοντάδων μm σε μικροσκοπική, χιλιοστών σε μακροσκοπική κίνηση) με περιορισμένα μέσα (απλή κάμερα κινητού).

# Μελλοντική Εργασία

## ΑΝΑΒΑΘΜΙΣΗ & ΛΟΓΙΣΜΙΚΟ

➢Γενική Βελτίωση Hardware & Εργαλείων Παρακολούθησης.

### ➢Ανάπτυξη πιο ανεπτυγμένων Αλγορίθμων Ελέγχου και

Πλοήγησης.

### ➢Ενσωματωμένοι νέοι Αισθητήρες για Αυξημένη Αυτονομία

# Ευχαριστώ για την προσοχή σας!

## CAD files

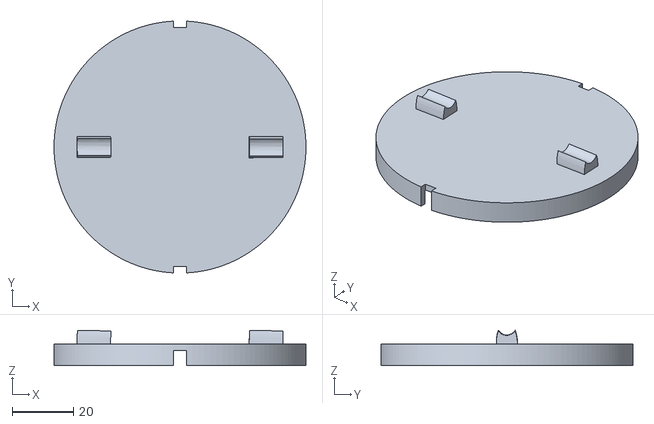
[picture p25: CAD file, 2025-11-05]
CAD_schematics/base_upper_v6.stl
82.0 x 81.9 x 11.5

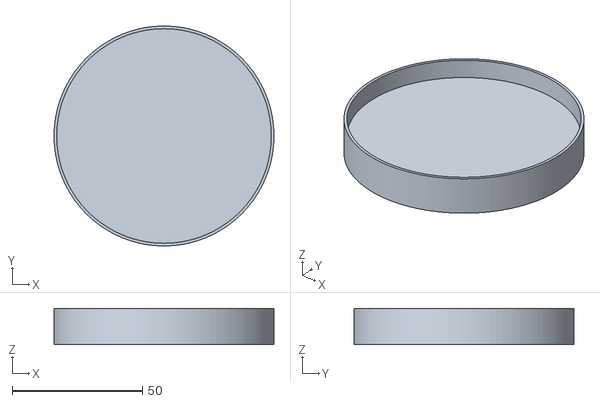
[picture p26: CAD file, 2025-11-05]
CAD_schematics/base_down_v6_2_holes.stl
84.5 x 84.5 x 14.0

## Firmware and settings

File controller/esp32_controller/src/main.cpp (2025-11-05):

#include <WiFi.h>
#include <WiFiUdp.h>
#include <Arduino.h>
#include <math.h>

const char* ssid = "OnePlus Nord 3 5G";
const char* password = "6982786930";

WiFiUDP udp;
const char* debugPC_IP = "192.168.234.227"; 
const int debugPort = 9999; 

const unsigned int udpPort = 1234;  
char incomingPacket[255]; 

char movmentState = 'S';
char lastMovementState = 'S';
char command;
//DRIVER A-J
#define HN1_PIN_B 32 //channel 3
#define LN1_PIN_B 33
#define LN2_PIN_B 19
#define HN2_PIN_B 18 // channel 0

int channel_B_HN1 = 3;
int channel_B_HN2 = 0;

//DRIVER M-W
#define HN1_PIN_A 17 //channel 1
#define LN1_PIN_A 21
#define LN2_PIN_A 22
#define HN2_PIN_A 23 //channel 2
// ----------------------------

int channel_A_HN1 = 1;
int channel_A_HN2 = 2;

// Sensor Pins
//B-F B
#define SENSOR_PIN_B 26

//R-V A

#define SENSOR_PIN_A 27

// Voltage Settings
#define MAX_VOLTAGE 1.5


const float a = -34.013918;
const float b = 123.639060;
const float c = -52.468123;
const float d = 15.099873;
//motor parameters and constants
const float Kt =0.0008373;
const float J = 3.4375e-09;
const float cf = 1.17222e-05;
const float b_damp = 2.61675e-08;
const float R = 10.71;
const float m = 0.0011;
const float g = 9.81;
const float r = 0.0025;

// PWM Configuration
const int pwmFrequency = 100;
const int pwmResolution = 8; 

// Global Variables for Motor A
volatile int pulseCountA = 0;
float targetVoltageA = 0.0; 
unsigned long lastTimeA = 0;
float rpmA = 0.0;
float rpmsA[17];
int indexA = 0;

// Global Variables for Motor B
volatile int pulseCountB = 0;
float targetVoltageB = 0.0; 
unsigned long lastTimeB = 0;
float rpmB = 0.0;
float rpmsB[17];
int indexB = 0;

// General Configuration
const float voltageStep = 0.1; // Voltage increment
const unsigned long delayBetweenSteps = 10; // Delay between measurements (ms)
const unsigned long debounceTimeA = 100; // Debounce time in milliseconds
const unsigned long debounceTimeB = 100;
volatile unsigned long lastPulseTimeA = 0;
volatile unsigned long lastPulseTimeB = 0;
const int pulsesPerRev =2;



float Kp_B = 37.77;  
float Ki_B = 479.26;  

float Kd_B = 0.0;
float errorB_prev = 0, integralB = 0;

float Kp_A = 37.77;  
float Ki_A = 479.26;  
float Kd_A = 0.0;
float errorA_prev = 0, integralA = 0;


unsigned long lastPIDTime = 0;
const int pidInterval = 8; 
float dt = pidInterval/1000.0;

float const setpointA_base = 595;
float const setpointB_base = 695;  

float setpointA = setpointA_base;
float setpointB = setpointB_base;

const float rpmIncrement = 45.0;
void sendDebugMessage(String message);
void IRAM_ATTR countPulseA();
void IRAM_ATTR countPulseB();
int dutyCycle(float volt);
void initialize_pins();
void motorA_right();
void motorA_left();
void motorB_right();
void motorB_left();
void forward_synchronous();
void backward_synchronous();
void rotation_left();
void rotation_right();

void stop_motors();
void getARPM();
void getBRPM();
float computePID(float setpoint, float input, float Kp, float Ki, float Kd,
                 float &integral, float &prevError, float dt);
void updateMotors();

void sendDebugMessage(String message) {
    udp.beginPacket(debugPC_IP, debugPort);
    udp.print(message);
    udp.endPacket();
}

void IRAM_ATTR countPulseA() {
    unsigned long currentTime = micros();
    if (currentTime - lastPulseTimeA > debounceTimeA) {
        pulseCountA++;
        lastPulseTimeA = currentTime;
    }
}

void IRAM_ATTR countPulseB() {
    unsigned long currentTime = micros();
    if (currentTime - lastPulseTimeB > debounceTimeB) {
        pulseCountB++;
        lastPulseTimeB = currentTime;
    }
}

template <typename T> int sign(T val) {
    return (T(0) < val) - (val < T(0));
}

int dutyCycle(float volt) {
    volt = (volt > MAX_VOLTAGE) ? MAX_VOLTAGE : volt;
    int duty = (int)((a * pow(volt, 3)) + (b * pow(volt, 2)) + c*volt + d);
   
    return constrain(duty, 0, 255); 
}

void initialize_pins(){
  pinMode(SENSOR_PIN_A, INPUT_PULLUP);
  attachInterrupt(digitalPinToInterrupt(SENSOR_PIN_A), countPulseA, FALLING);

  pinMode(SENSOR_PIN_B, INPUT_PULLUP);
  attachInterrupt(digitalPinToInterrupt(SENSOR_PIN_B), countPulseB, FALLING);

  pinMode(HN1_PIN_A, OUTPUT);
  pinMode(LN1_PIN_A, OUTPUT);
  pinMode(HN2_PIN_A, OUTPUT);
  pinMode(LN2_PIN_A, OUTPUT);
  
  pinMode(HN1_PIN_B, OUTPUT);
  pinMode(LN1_PIN_B, OUTPUT);
  pinMode(HN2_PIN_B, OUTPUT);
  pinMode(LN2_PIN_B, OUTPUT);

  digitalWrite(HN1_PIN_A, LOW);
  digitalWrite(LN1_PIN_A, LOW);
  digitalWrite(HN2_PIN_A, LOW);
  digitalWrite(LN2_PIN_A, LOW);

  digitalWrite(HN1_PIN_B, LOW);
  digitalWrite(LN1_PIN_B, LOW);
  digitalWrite(HN2_PIN_B, LOW);
  digitalWrite(LN2_PIN_B, LOW);


  ledcSetup(channel_B_HN2, pwmFrequency, pwmResolution);
  ledcAttachPin(HN2_PIN_B, channel_B_HN2);

  ledcSetup(channel_A_HN1, pwmFrequency, pwmResolution);
  ledcAttachPin(HN1_PIN_A, channel_A_HN1);

  ledcSetup(channel_A_HN2, pwmFrequency, pwmResolution);
  ledcAttachPin(HN2_PIN_A, channel_A_HN2);

  ledcSetup(channel_B_HN1, pwmFrequency, pwmResolution);
  ledcAttachPin(HN1_PIN_B, channel_B_HN1);

}

void setup() {
    Serial.begin(9600);
    WiFi.begin(ssid, password);

    Serial.print("Connecting to WiFi...");
    while (WiFi.status() != WL_CONNECTED) {
        delay(500);
        Serial.print(".");
    }
    
    Serial.println("\nConnected!");
    Serial.print("ESP32 IP Address: ");
    Serial.println(WiFi.localIP());  

    udp.begin(udpPort);
    Serial.printf("Listening on port %d\n", udpPort);
    initialize_pins();
    Serial.println("WiFi UDP Setup Complete");

    
}
void motorA_right(){
  
  digitalWrite(LN1_PIN_A, LOW);
  digitalWrite(HN2_PIN_A, LOW);
  digitalWrite(LN2_PIN_A, HIGH); 
  ledcWrite(channel_A_HN1, dutyCycle(targetVoltageA));

}

void motorA_left(){
  Serial.println(targetVoltageA);
  digitalWrite(LN1_PIN_A, HIGH);
  digitalWrite(LN2_PIN_A, LOW);
  digitalWrite(HN1_PIN_A, LOW);
  ledcWrite(channel_A_HN2, dutyCycle(targetVoltageA));
}

void motorB_right(){
  
  digitalWrite(LN1_PIN_B, LOW);
  digitalWrite(HN2_PIN_B, LOW);
  digitalWrite(LN2_PIN_B, HIGH); 
  
  ledcWrite(channel_B_HN1, dutyCycle(targetVoltageB));
}

void motorB_left(){
  
  digitalWrite(LN2_PIN_B, LOW);
  digitalWrite(HN2_PIN_B, LOW);
  digitalWrite(LN1_PIN_B, HIGH); 
  Serial.println(dutyCycle(targetVoltageB));
  ledcWrite(channel_B_HN2, dutyCycle(targetVoltageB));
}

void forward_synchronous(){
  getARPM();
  motorA_right();

  getBRPM();
  motorB_left();
}

void backward_synchronous(){
  getARPM();
  motorA_left();
  delay(5);
  getBRPM();
  motorB_right();
}

void rotation_left(){
  getARPM();
  motorB_right();
  delay(5);
  getBRPM();
  motorA_right();
}

void rotation_right(){
  getARPM();
  motorB_left();
  delay(5);
  getBRPM();
  motorA_left();
}

void stop_motors(){
  digitalWrite(HN1_PIN_A, LOW);
  digitalWrite(HN2_PIN_A, LOW);
  digitalWrite(LN1_PIN_A, LOW);
  digitalWrite(LN2_PIN_A, LOW);
  
  digitalWrite(HN1_PIN_B, LOW);
  digitalWrite(HN2_PIN_B, LOW);
  digitalWrite(LN1_PIN_B, LOW);
  digitalWrite(LN2_PIN_B, LOW);

  ledcWrite(channel_A_HN1, 0); 
  ledcWrite(channel_A_HN2, 0); 
  ledcWrite(channel_B_HN1, 0); 
  ledcWrite(channel_B_HN2, 0); 
  delay(1);
}

void getARPM(){
  unsigned long currentTimeA = millis();
        if (currentTimeA - lastTimeA >= delayBetweenSteps) {
            float timeInSeconds = (currentTimeA - lastTimeA) / 1000.0;
            lastTimeA = currentTimeA;

            noInterrupts();
            int pulses = pulseCountA;
            pulseCountA = 0;
            interrupts();
            
             rpmA = (pulses / (float)pulsesPerRev) * (60.0 / timeInSeconds);
             rpmA = rpmA*(2*PI/60);
            
            rpmsA[indexA++] = rpmA;
            if (indexA >= 17) indexA = 0;

            String message = "Motor A - Voltage (V): "+ String(targetVoltageA) +
                            ", RPM: " + String(rpmA);
            sendDebugMessage(message);
        }
}

void getBRPM(){
  unsigned long currentTimeB = millis();
  if (currentTimeB - lastTimeB >= delayBetweenSteps) {
            float timeInSeconds = (currentTimeB - lastTimeB) / 1000.0;
            lastTimeB = currentTimeB;

            noInterrupts();
            int pulses = pulseCountB;
            pulseCountB = 0;
            interrupts();

            rpmB = (pulses / (float)pulsesPerRev) * (60.0 / timeInSeconds);
            rpmB = rpmB*(2*PI/60);
            
            rpmsB[indexB++] = rpmB;
            if (indexB >= 17) indexB = 0;

            String message = "Motor B - Voltage (V): "+ String(targetVoltageB) +
                            ", RPM: " + String(rpmB);
            sendDebugMessage(message);
            Serial.println(message);

  }
}



void updateMotors(){
  if (movmentState != lastMovementState) {
    stop_motors();

    Serial.print("Preparing for Direction Change \n");  
    lastMovementState = movmentState;
  }
  switch(movmentState){
    case 'F':
      forward_synchronous();
      break;
    case 'B':
      backward_synchronous();
      break;
    case 'L':
      rotation_left();

      break;
    case 'R':
      rotation_right();

      break;
    case 'S':
      stop_motors();
      break;
    default:
      stop_motors();
      break;
  }
}

float error_sum =0;
float computePID(float setpoint, float input, float Kp, float Ki, float Kd,
                 float &integral, float &prevError, float dt){
    static float theta = 0.0;
    
    float derivative = 0;
    float error = setpoint - input;
    integral += error*dt;
    derivative = (error - prevError)/dt; 
    prevError = error;


    float output = -Kp*input + Ki*integral;
    Serial.printf("\nOutput at compute: %f",output);
    
    float out_volt = ((pow(Kt,2)+R*b_damp)/Kt)*input + R*cf*sign(input)/Kt + J*R*output/Kt +R*m*g*r*sin(theta);
Serial.printf("\nOutput at compute: %f\n",out_volt);
    return constrain(out_volt,0,1.5);
}



void loop() {
  
    int packetSize = udp.parsePacket();
    if (packetSize) {
        int len = udp.read(incomingPacket, sizeof(incomingPacket) - 1);
        if (len > 0) {
            incomingPacket[len] = 0; 
        }

        command = incomingPacket[0];
    
        Serial.println("Received command: "+command);
        if (strcmp(incomingPacket, "PING") == 0) {
                    udp.beginPacket(udp.remoteIP(), udp.remotePort());
                    udp.print("PONG");
                    udp.endPacket();
                    sendDebugMessage("Received PING, sent PONG");
                    return;  
                }
        switch (command) {
            case 'F':
                movmentState = 'F';
                sendDebugMessage("Moving Forward");
                break;
            case 'B':
                movmentState = 'B';
                sendDebugMessage("Moving Backward");
                break;
            case 'L':
          
                movmentState = 'F';

                sendDebugMessage("Rotating Left");
               
                setpointA = setpointA_base+ rpmIncrement;
                setpointB =setpointB_base -rpmIncrement;
              
                break;
            case 'R':
               
                movmentState = 'F';

                setpointA = setpointA_base -  rpmIncrement;
                setpointB =setpointB_base + rpmIncrement;

                break;
            case '+':
   
                setpointA += rpmIncrement;
                setpointB += rpmIncrement;
   
                
                sendDebugMessage("Increasing Speed");
                break;
            case '-':
        
                setpointA -= rpmIncrement;
                setpointB -= rpmIncrement;

                sendDebugMessage("Decreasing Speed");
                break;
            case 'S':
                movmentState = 'S';
                sendDebugMessage("Stopping Motors");
                break;
            case 'C':
                setpointA = setpointA_base;
                setpointB = setpointB_base;
                movmentState = 'F';
   
                break;
            default:
                sendDebugMessage("Unknown Command");
                break;
        }
    }
 
        if(command&&command!='S'){
         
            lastPIDTime = millis();
            if (setpointA > 0) {
           
            targetVoltageA = computePID(setpointA, rpmA, Kp_A, Ki_A, Kd_A, integralA, errorA_prev, dt);
          } else {
            targetVoltageA = 0;
          }  
         

             if (setpointB > 0) {
                
                targetVoltageB = computePID(setpointB, rpmB, Kp_B, Ki_B, Kd_B, integralB, errorB_prev, dt);
            
              } else {
                targetVoltageB = 0; 
                
            }
         
        }updateMotors();  

    delay(8);
}




 

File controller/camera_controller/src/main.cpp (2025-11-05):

#include <opencv2/opencv.hpp>
#include <iostream>
#include <vector>
#include <cmath>
#include <string>
#include <fstream>
#include <limits>
#include <filesystem>
#include <memory>

#include "camera_calibrator.h"
#include "udp_client.h"
#include "macro_controller.h"
#include "micro_controller.h"

namespace fs = std::filesystem;
using namespace std;

cv::Point2f userTarget(-1, -1);
bool targetSelected = false;

void onMouse(int event, int x, int y, int, void*) {
    if (event == cv::EVENT_LBUTTONDOWN) {
        userTarget = cv::Point2f(x, y);
        targetSelected = true;
        std::cout << "Target selected at: (" << x << ", " << y << ")" << std::endl;
    }
}

bool initializeVideoRecording(cv::VideoCapture& cap, cv::VideoWriter& writer) {
    char response;
    std::cout << "Do you want to record the session? (y/n): ";
    std::cin >> response;

    if (response != 'y' && response != 'Y') {
        return false;
    }

    std::string videoFilename;
    std::cout << "Enter a name for the video file (without extension): ";
    std::cin >> videoFilename;

    fs::path mainFolder = "fvideo";
    fs::path sessionFolder = mainFolder / videoFilename;

    try {
        fs::create_directories(sessionFolder);
    } catch (const std::exception& e) {
        std::cerr << "Error creating folders: " << e.what() << std::endl;
        return false;
    }

    fs::path fullPath = sessionFolder / (videoFilename + ".avi");

    int codec = cv::VideoWriter::fourcc('M', 'J', 'P', 'G');
    double fps = 20.0;
    cv::Size frameSize(
        static_cast<int>(cap.get(cv::CAP_PROP_FRAME_WIDTH)),
        static_cast<int>(cap.get(cv::CAP_PROP_FRAME_HEIGHT))
    );

    writer.open(fullPath.string(), codec, fps, frameSize, true);
    if (!writer.isOpened()) {
        std::cerr << "Error: Could not open video file for writing: " << fullPath << std::endl;
        return false;
    }

    std::cout << "Recording video to: " << fullPath << std::endl;
    return true;
}

int main(int argc, char* argv[]) {
    double cmPerPixelRatio = 0.0;
    const string calibrationFilename = "calibration_data.txt";
    bool performCalibration = false;
    bool useMacroController = true; // Default to macro

    // Parse command line arguments
    for (int i = 1; i < argc; i++) {
        if (std::string(argv[i]) == "--calibrate") {
            performCalibration = true;
        } else if (std::string(argv[i]) == "--micro") {
            useMacroController = false;
            cout << "Using Micro Controller" << endl;
        } else if (std::string(argv[i]) == "--macro") {
            useMacroController = true;
            cout << "Using Macro Controller" << endl;
        }
    }

    CameraCalibrator calibrator(2);

    if (performCalibration){
        cout << "Forcing camera calibration..."<<endl;
        calibrator.runCalibration();
        if(calibrator.getCmPerPixelRatio()>0){
            calibrator.saveCalibration(calibrationFilename);
            cmPerPixelRatio = calibrator.getCmPerPixelRatio();
        } else {
            cerr<<"Calibration failed or was interrupted. Exiting"<<endl;
            return -1;
        }
        try {
            cv::destroyWindow("Camera Feed - Click Two Points on Ruler");
        } catch (...) {
            cerr << "Warning: Tried to destroy a window that wasn't created." << endl;
        }
    } else {
        if(!calibrator.loadCalibration(calibrationFilename)){
            cout <<"Calibration data missing. Initiating Calibration..."<<endl;
            calibrator.runCalibration();
            if (calibrator.getCmPerPixelRatio() > 0) {
                calibrator.saveCalibration(calibrationFilename);
                cmPerPixelRatio = calibrator.getCmPerPixelRatio();
            } else {
                cerr << "Calibration failed or was interrupted. Exiting." << endl;
                return -1;
            }
        } else {
            cmPerPixelRatio = calibrator.getCmPerPixelRatio();
        }
    }

    if(cmPerPixelRatio<=0){
        cerr<<"Invalid pixel to cm ratio"<<endl;
        return -1;
    }
    cout << "Using Centimeter per Pixel Ratio: "<<cmPerPixelRatio<<" cm/pixel"<<endl;

    string esp_ip ="192.168.234.188";
    int esp_port = 1234;
    UdpClient udpClient(esp_ip, esp_port);

    if (!udpClient.isInitialized()) {
        cerr << "Failed to initialize UDP Client. Exiting." << endl;
        return -1;
    }

    // Create appropriate controller based on command line argument
    std::unique_ptr<RobotController> controller;
    if (useMacroController) {
        controller = std::make_unique<MacroController>(cmPerPixelRatio, &udpClient);
    } else {
        controller = std::make_unique<MicroController>(cmPerPixelRatio, &udpClient);
    }

    cv::VideoCapture cap(2);
    if (!cap.isOpened()) {
        cerr << "Error: Could not open the camera. " << endl;
        return -1;
    }
    cout << "Camera opened successfully!" << endl;

    cv::VideoWriter videoWriter;
    bool recordVideo = initializeVideoRecording(cap, videoWriter);

    std::this_thread::sleep_for(std::chrono::seconds(1));
    
    ofstream logFile("robot_path.csv");
    logFile << "time,controller_type,rear_x,rear_y,front_x,front_y,target_x,target_y,debug_angle,debug_distance,command\n";

    int frame_count = 0;
    cv::namedWindow("Robot View", cv::WINDOW_AUTOSIZE);
    cv::setWindowProperty("Robot View", cv::WND_PROP_FULLSCREEN, cv::WINDOW_FULLSCREEN);
    cv::setMouseCallback("Robot View", onMouse, nullptr);
    auto startTime = std::chrono::steady_clock::now();
    while(true){
        cv::Mat frame, blurred, hsv;
        
        try{
            if (!cap.read(frame)) { 
                cerr << "Warning: Could not read frame from camera. Retrying..." << endl;
                std::this_thread::sleep_for(std::chrono::milliseconds(100)); 
                if (!cap.read(frame)) { 
                    cerr << "Error: Failed to read frame after retry. Camera might be disconnected. Exiting." << endl;
                    break; 
                }
            }
            
            if (frame.empty() || frame.cols == 0 || frame.rows == 0 || frame.channels() == 0) {
                cerr << "Warning: Captured frame is empty or invalid. Skipping frame." << endl;
                continue; 
            }
            
            int key = cv::waitKey(30);
            if (key == 27) { // ESC key
                udpClient.sendCommand('S'); 
                break;
            }

            cv::GaussianBlur(frame, blurred, cv::Size(5,5), 0);
            cv::cvtColor(blurred, hsv, cv::COLOR_BGR2HSV);
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
